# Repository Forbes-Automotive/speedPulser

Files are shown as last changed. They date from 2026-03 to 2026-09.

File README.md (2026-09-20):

# SpeedPulser

The SpeedPulser converts digital speed pulses from a gearbox hall sensor (or a [Can2Cluster](https://forbes-automotive.com) signal) into a 10 kHz PWM signal that drives a BLDC motor — giving life back to an OEM analog speedometer without a mechanical cable. It is fully open-source, WiFi-configurable, and calibrated per cluster type so the needle reads accurately across the available speed range of the motor.

It is based on a **LOLIN C3 Mini (ESP32-C3)** and uses a **TY3816B** BLDC motor driven via a native LEDC hardware PWM channel.

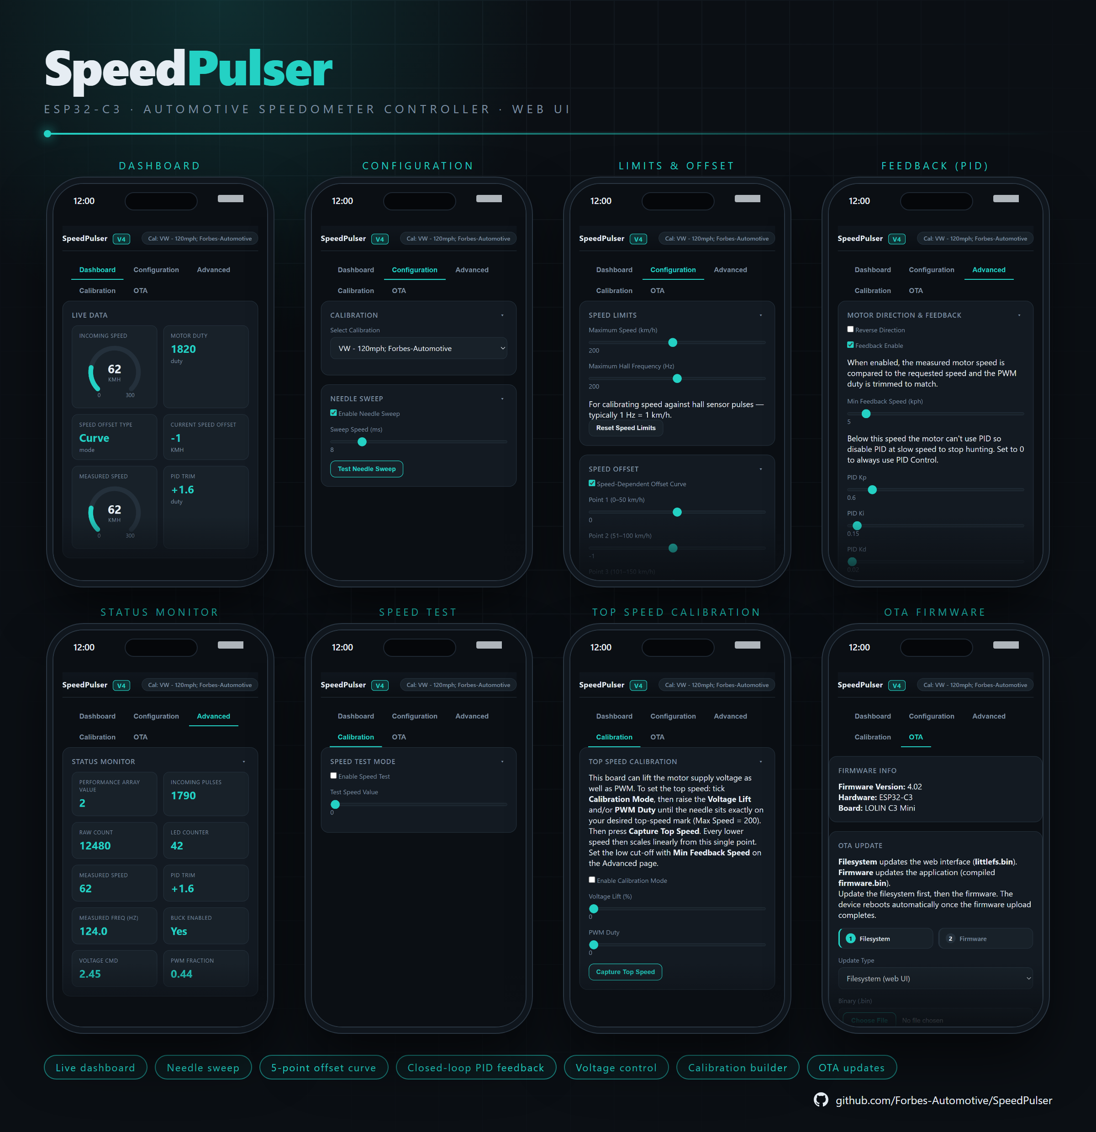
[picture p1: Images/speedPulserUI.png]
SpeedPulser Web UI — dashboard, configuration, limits & offset, PID feedback, status monitor, speed test, top-speed calibration and OTA


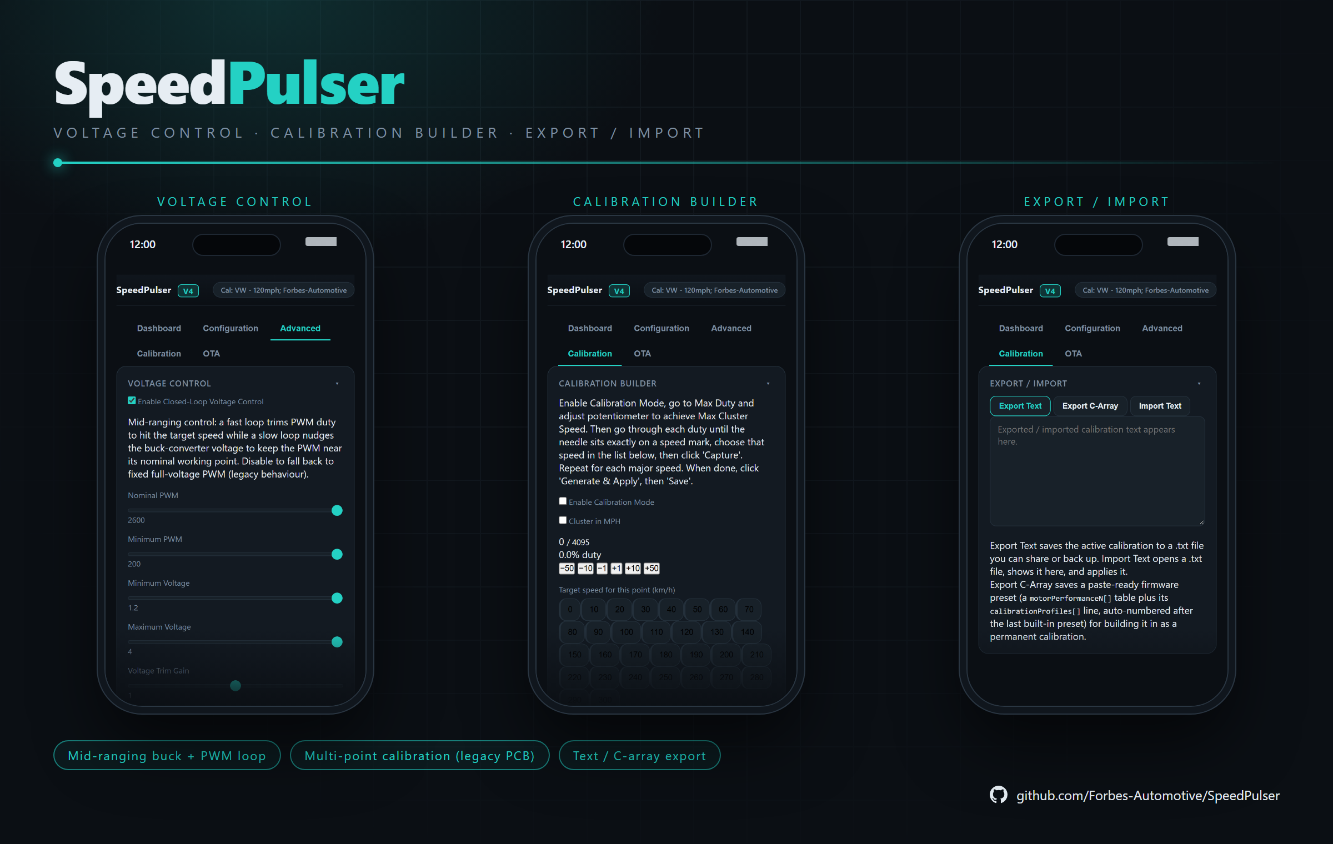
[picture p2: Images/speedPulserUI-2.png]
SpeedPulser Web UI — voltage control, calibration builder and export / import


---

## Features at a Glance

| Feature | Detail |
|---|---|
| Speed input | 5V / 12V square-wave (hall sensor or Can2Cluster) |
| Motor output | 10 kHz hardware PWM, 12-bit resolution |
| Closed-loop feedback | PID trims duty from the motor feedback pin (optional) |
| Calibration profiles | 18 built-in (VW, Ford, Fiat, Merc, Smiths, Opel, VW Bay) |
| Custom calibration | Calibration Builder — capture, generate, save, export/import |
| Calibration Curve | Live duty-vs-speed curve with the current operating point on the Dashboard |
| Status Monitor | Live measured speed, PID trim and actual motor speed (Hz) |
| WiFi UI | Web app type interface |
| Needle sweep | Configurable on power-up |
| Speed offset | Global fixed offset **or** 5-point speed-dependent curve |
| OTA updates | Firmware upload from the browser |
| Power management | Auto WiFi-off + CPU scaling after 1 min idle |
| Remembers settings | All settings stored to ESP32 Preferences (NVS/EEPROM) |

---

## Supported Models

| Cluster | Range | Calibration by |
|---|---|---|
| VW MK1 / MK2 Golf | 120 mph | Martin Springell |
| VW MK1 / MK2 Golf | 120 mph | Forbes Automotive |
| VW MK1 / MK2 Golf | 120 mph | Tara |
| VW MK1 / MK2 Golf | 140 mph | Forbes Automotive |
| VW MK1 / MK2 Golf | 160 mph | Forbes Automotive |
| VW MK1 / MK2 Golf | 300 kph (1.8T) | Forbes Automotive |
| VW Bay VDO | 90 mph | Community |
| Ford Escort | 120 mph (var. 1) | Forbes Automotive |
| Ford Escort | 120 mph (var. 2 — Darren) | Community |
| FIAT Uno | 40–160 mph | Forbes Automotive |
| FIAT Uno | 20–110 mph | Forbes Automotive |
| Mercedes W123 | 120 mph | Forbes Automotive |
| Smiths 5/8" | 70 mph | Forbes Automotive |
| Smiths 5/8" | 90 mph | Forbes Automotive |
| Smiths 5/8" | 150 mph | Forbes Automotive |
| Opel Manta A-72 | 200 km/h | Forbes Automotive |

> Users are actively encouraged to submit new models, calibrations, or corrections via GitHub or Discord.

---

## Purchase

Pre-assembled SpeedPulser units are available here: [SpeedPulser — Forbes Automotive](https://forbes-automotive.com/products/speedpulser)

---

## More Detailed Instructions

The PDF Installation Guide on GitHub provides full step-by-step hardware fitting instructions.

---

## Hardware Overview

### PCB

The pre-assembled PCB:

SpeedPulser Board Overview

---

### Power Supply & Hall Sensor Input

The three-pin **Input** connector on the bottom edge of the PCB accepts 12V battery power and the speed signal:

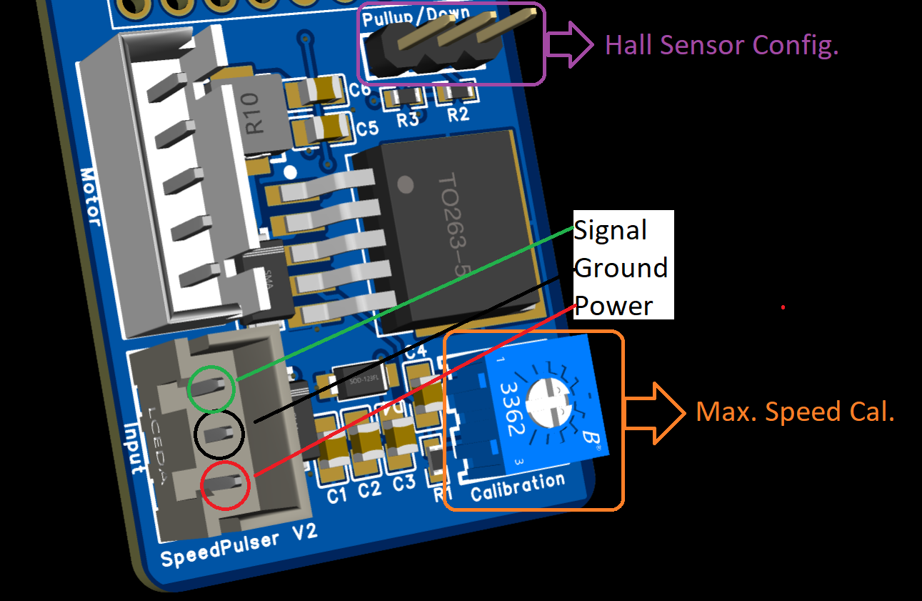
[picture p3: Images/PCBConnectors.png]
PCB Input & Motor Connectors


| Pin | Signal | Notes |
|-----|---|---|
| 1 | PWR_IN (12 V) | Closest to board edge; connect to ignition-switched 12 V |
| 2 | GND | Common ground |
| 3 | Speed Signal | 5 V or 12 V square wave from hall sensor or Can2Cluster |

> **Pull-up / Pull-down jumper:** Different hall sensors require either a pull-up or pull-down resistor. A 2-way jumper header on the PCB selects this. If the SpeedPulser is not registering incoming pulses, swap the jumper position. Sensors with an internal resistor can have the jumper removed entirely.

An on-board adjustable **LM2596S** buck converter steps the 12V supply down to approximately 9V to power the motor, keeping the motor's operating range and torque within spec across the full speed scale.

---

### Motor Connector

The five-pin **Motor** connector on the top edge of the PCB:

| Pin | Signal | Notes |
|-----|---|---|
| 1 | Motor Power | Black — 5–9 V (set via on-board trimmer) |
| 2 | Motor Feedback | White — BLDC feedback pulse; read on GPIO 4 for closed-loop PID (optional) |
| 3 | Motor Direction | Green — LOW (normal); enable Reverse to flip needle direction — HIGH (reversed) |
| 4 | Motor Ground | White — motor ground |
| 5 | Motor PWM | 10 kHz PWM from ESP32 (via NPN level-shifter to 4V) |

---

### Coupler Installation

Motors are supplied with the coupler pre-fitted; the final drive pin and securing pins are included separately.

1. Remove the motor from the coupler housing.
2. Align the drive pin into the coupler recess and press home — a few light taps should seat it fully.
3. A spare coupler is supplied. Couplers are 3D printed; slight alignment variation is normal. A brief gentle heat application (≤ 100 °C) can encourage a true run.
4. If excessive vibration causes the coupler to loosen, a small drop of super-glue will fix it permanently — confirm it runs true before the glue sets.

---

### Trimming the Drive Shaft

Drive shafts are supplied longer than required. Trim to suit your cluster, typically flush with the motor housing. **Confirm the shaft does not bottom out in the cluster before tightening.**

---

### Fine-Tuning the Coupler

Once the motor is assembled, slide it over the OEM cluster shaft. Check:

- The drive pin engages cleanly
- The motor spins freely by hand
- The pin length is sufficient to engage the cluster but does not prevent the housing from seating fully

Take time here — good fitment minimises noise and extends coupler life.

> Couplers are 3D printed and every motor / housing / cluster pairing wears in slightly differently. Expect to revisit the on-board potentiometer once after a few hours of running so the top-end reading still hits full-scale cleanly.

---

## WiFi & Web Interface

Connect to the **`SpeedPulser`** WiFi access point (open network) and navigate to **`192.168.1.1`** or **`speedpulser.local`** in a browser.

The interface is a single-page app served from the ESP32's LittleFS flash partition, built on Forbes Automotive's shared dark theme (the same look used across OpenHaldex, Can2Cluster, SpeedPulserPro, can2rpm, the MQB Steering Wheel Controller and AirLift Controller). Settings are applied in real time and saved to EEPROM automatically every 2 seconds. Current firmware version: **4.01**.

**Status colours:** most tiles use plain text rather than colour, but a per-tile dial gauge (Incoming Speed / Motor Duty) turns **orange/amber** whenever **Speed Test Mode** or **Calibration Mode** is driving the motor — a reminder that the value shown is a synthetic test value, not a live vehicle reading. A missing motor-feedback signal (legacy PCBs without the feedback circuit) shows as plain **N/A** rather than a coloured warning.

### Dashboard Tab

Live read-outs updated automatically:

| Field | Description |
|---|---|
| Incoming Speed | Speed value calculated from incoming hall-sensor pulses (km/h or mph) |
| Motor Duty | PWM duty cycle currently applied to the motor |
| Measured Speed | Speed derived from the motor fedback pin when feedback is enabled |
| PID Trim | Duty correction the feedback loop is currently applying |
| Speed Offset Type | Whether a *Global* or *Curve* offset is active |
| Current Speed Offset | The offset value applied at the current speed |

Below the read-outs is a **Calibration Curve** graph: a duty-vs-speed trace of the
active calibration with its captured points, plus a marker showing the point
currently being achieved — from the hall input, Speed Test Mode or Calibration Mode.

While **Speed Test Mode** is active, these fields switch to show the chosen test speed and resulting motor duty instead.

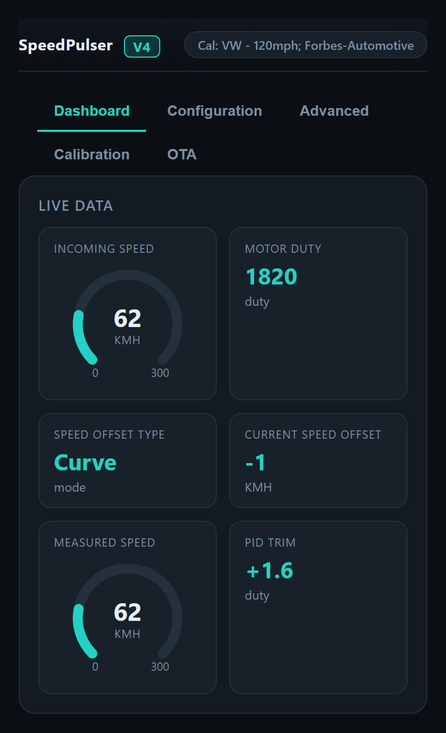
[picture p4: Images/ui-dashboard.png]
Dashboard tab — live data tiles (incoming speed, motor duty, offset type and value, measured speed, PID trim) and the calibration curve graph


> The bright dot on the graph is the point currently being achieved — from the hall input, Speed Test Mode or Calibration Mode — plotted against the active calibration's duty/speed curve (green dots = captured/sampled anchor points).

### Configuration Tab

| Setting | Description |
|---|---|
| Enable Needle Sweep | Triggers a full-scale needle sweep on power-up |
| Sweep Speed (ms) | Step delay in milliseconds: lower = faster sweep |
| Test Needle Sweep | Trigger a sweep immediately from the browser |
| Calibration Selection | Choose from 18 built-in cluster calibration profiles |
| Maximum Speed (km/h) | Upper end of the cluster's speed scale |
| Maximum Hall Frequency (Hz) | The input frequency that corresponds to Maximum Speed |
| Speed Offset Value | Fixed offset added to or subtracted from all speed readings |
| Positive Offset | Direction of the fixed offset (add or subtract) |
| Speed-Dependent Offset Curve | Enable a 5-point curve offset in place of the global offset |
| Cluster in MPH | Convert the km/h input signal to mph before looking up the motor duty |
| Average Filter Samples | Median smoothing window (1–10) for the incoming signal; higher = steadier but slower |

<p align="center">
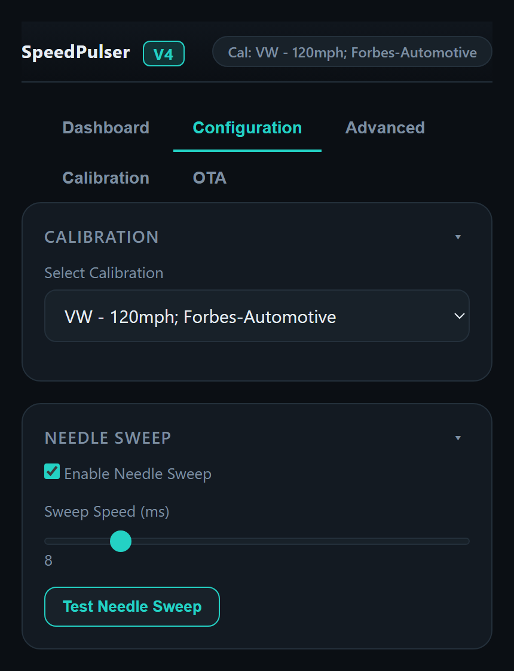
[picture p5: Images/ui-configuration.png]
Configuration tab — calibration selection and needle sweep
  
  &nbsp;&nbsp;
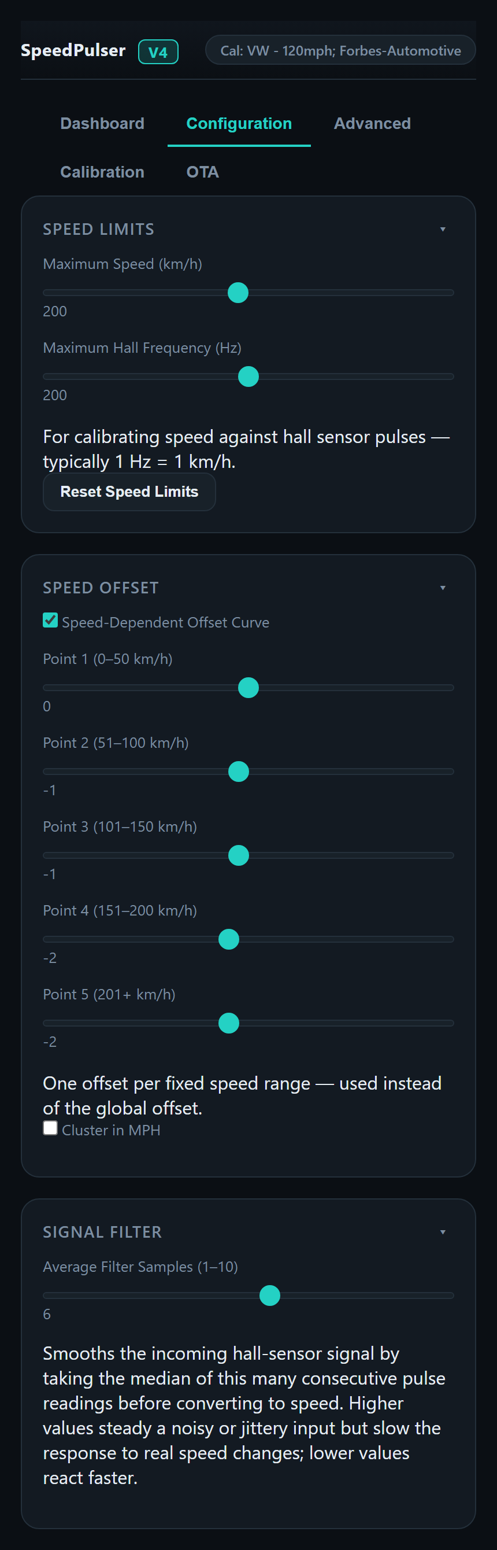
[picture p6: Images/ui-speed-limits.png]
Configuration tab — speed limits, the 5-point speed-dependent offset curve, cluster-in-MPH and the signal filter
  
</p>

*Configuration: calibration profile and needle sweep (left); speed limits, the offset curve (or fixed offset), MPH conversion and the median filter window (right).*

### Advanced Tab

| Setting | Description |
|---|---|
| Reverse Direction | Drive the direction pin HIGH to flip the motor direction |
| Feedback Enable | Turn the closed-loop PID duty trim on or off (**not available on legacy PCBs**) |
| Min Feedback Speed (km/h) | Below this speed the loop runs open-loop (feed-forward only) to stop low-speed hunting; 0 = always closed-loop |
| PID Kp / Ki / Kd | Feedback loop gains (defaults 0.15 / 1.3 / 0) |
| PID Deadband (Hz) | Feedback error (in Hz) ignored by the loop, to stop the needle dithering |
| Reset PID Defaults | Restore the tuned default gains |
| Voltage Control *(V4 PCB only)* | Enable the closed-loop **buck-converter voltage** trim and set its nominal / minimum PWM, voltage range, trim gain and loop gains |
| Performance Array Value | Index of the active calibration array |
| Incoming Pulses | Raw frequency value from the ISR |
| Raw Count | Number of samples accumulated so far |
| LED Counter | ISR pulse counter (also drives the onboard LED blink) |

<p align="center">
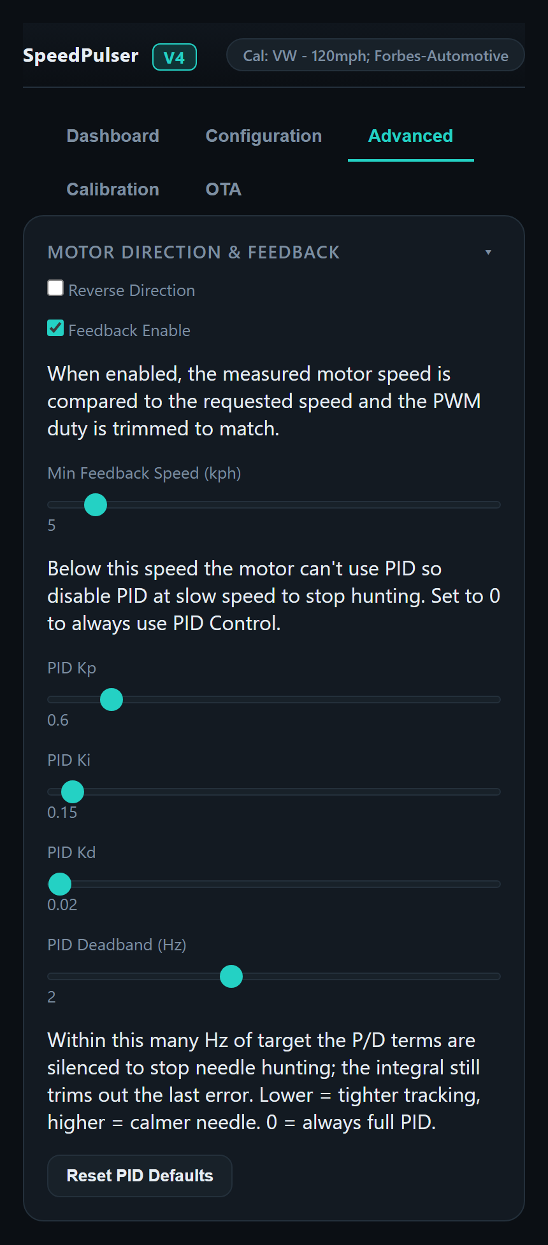
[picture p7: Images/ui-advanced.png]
Advanced tab — motor direction, feedback enable, min feedback speed, PID gains and deadband
  
  &nbsp;&nbsp;
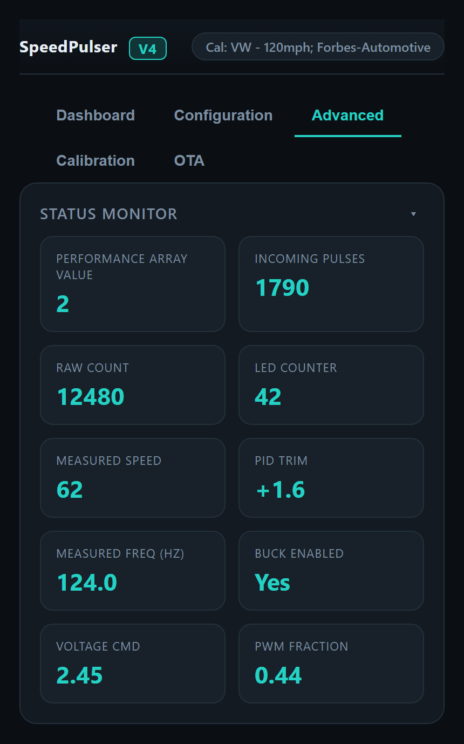
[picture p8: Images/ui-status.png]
Advanced tab — live status monitor: performance array, incoming pulses, raw count, LED counter, measured speed / frequency, PID trim, buck state, voltage command and PWM fraction
  
</p>
> **Reverse Direction** drives GPIO 10 HIGH instead of LOW, flipping the rotation direction for clusters whose motor is mounted the opposite way round.
> **Feedback Enable** turns the closed-loop PID trim on; the sliders below it tune the loop and **Reset PID Defaults** restores the tuned baseline (0.15 / 1.3 / 0). See [Closed-Loop Feedback (PID)](#closed-loop-feedback-pid) below for how it works.

On a **V4 PCB** the Advanced tab also shows **Voltage Control**. This is a mid-ranging scheme: the fast PID loop above trims PWM duty to hit the target speed, while a slow loop nudges the buck-converter voltage so the PWM stays near its **Nominal PWM** working point (between the **Minimum / Maximum Voltage** limits). Turn it off to fall back to fixed full-voltage PWM, i.e. legacy behaviour.

<p align="center">
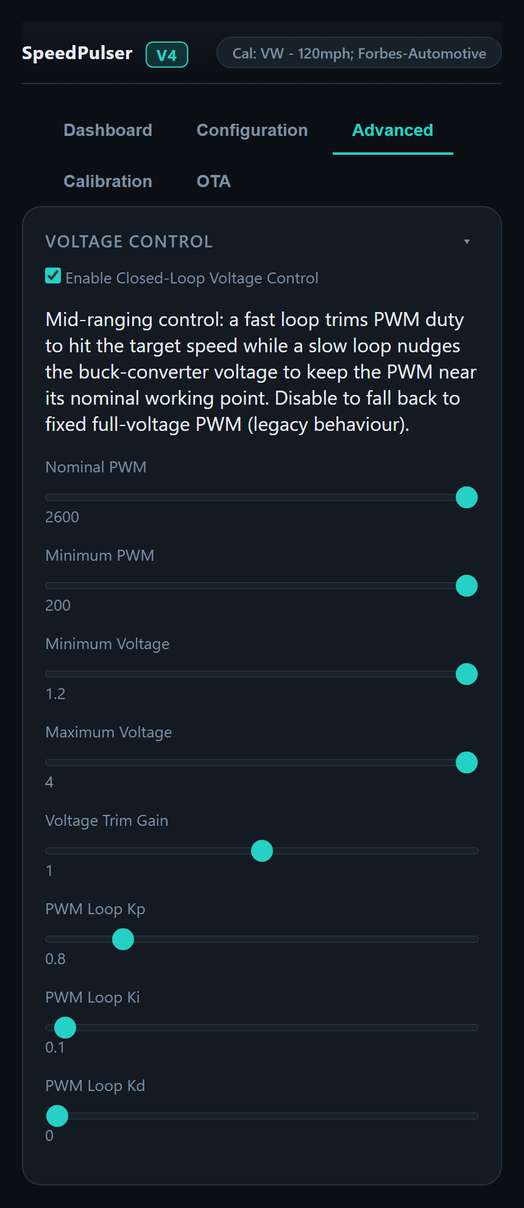
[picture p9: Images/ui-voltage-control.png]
Advanced tab — Voltage Control card: enable, nominal and minimum PWM, minimum / maximum voltage, trim gain and PWM loop gains
  
</p>

### Calibration Tab

Contains **Speed Test Mode**, **Export / Import** and — depending on the board — either the **Top Speed Calibration** card (V4 PCB, which can lift the motor supply voltage) or the multi-point **Calibration Builder** (earlier PCBs).

**Speed Test Mode**  
Locks the motor to a user-chosen speed so the cluster can be observed
without a speed signal. The chosen speed passes through the full offset and
calibration process, to give a realistic preview. With feedback enabled the closed
loop drives to that speed; the dashboard updates in real time to show the chosen speed
and the resulting motor duty.

**Top Speed Calibration** *(V4 PCB)*  
Tick **Enable Calibration Mode**, then raise **Voltage Lift** and/or **PWM Duty** until the
needle sits exactly on the top-speed mark (the Maximum Speed set on the Configuration tab)
and press **Capture Top Speed**. Every lower speed then scales linearly from that single
point; the low cut-off is **Min Feedback Speed** on the Advanced tab.

<p align="center">
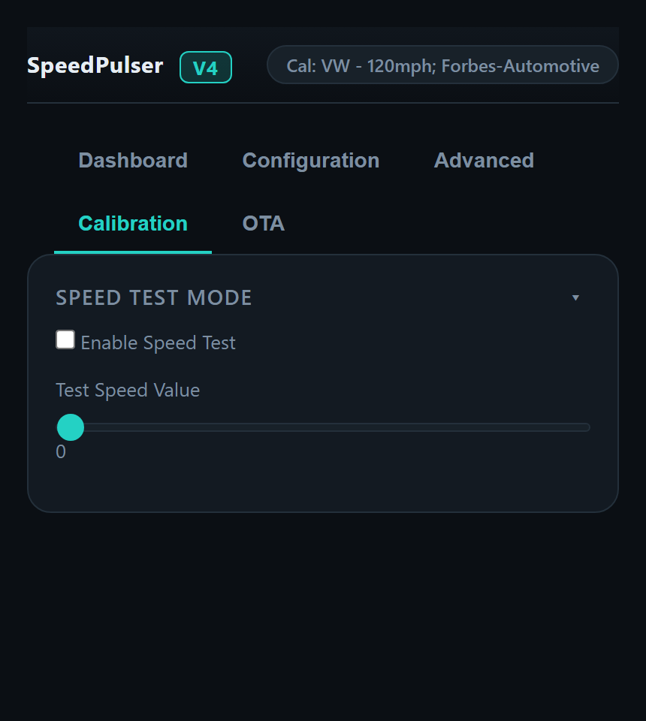
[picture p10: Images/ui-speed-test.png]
Calibration tab — Speed Test Mode with enable and test speed slider
  
  &nbsp;&nbsp;
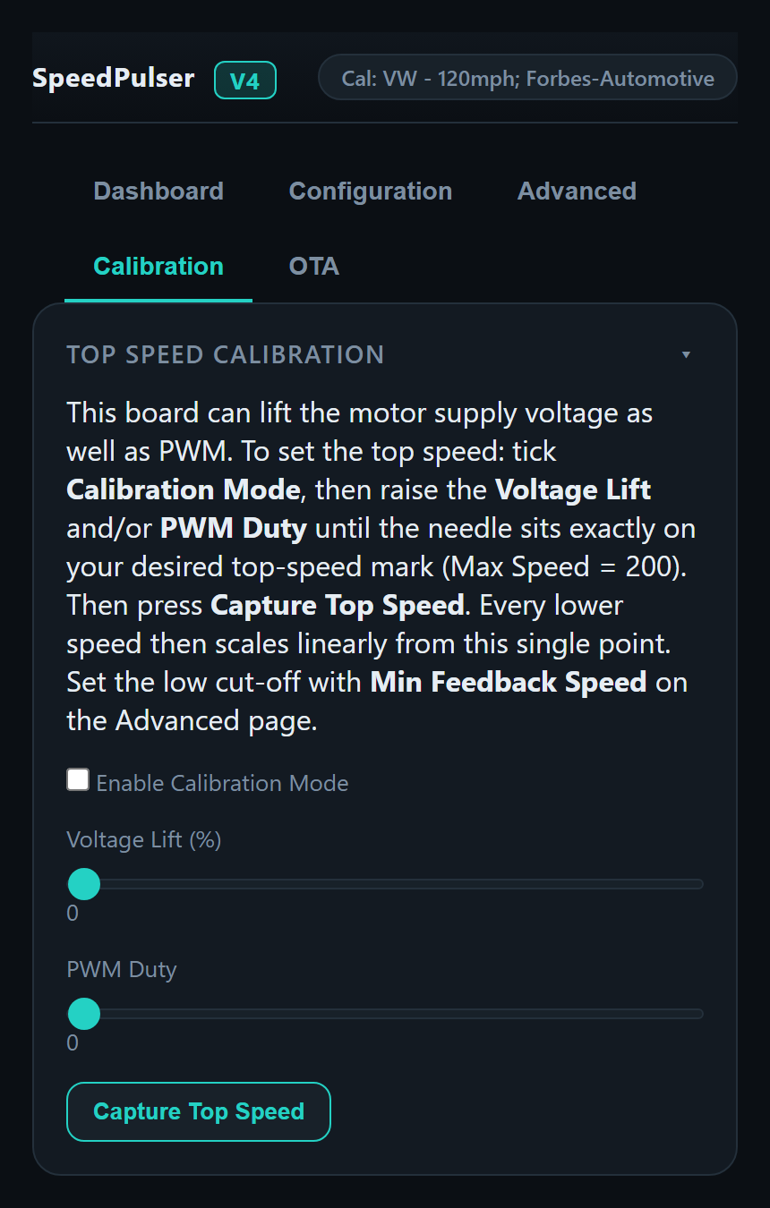
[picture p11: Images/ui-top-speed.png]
Calibration tab — Top Speed Calibration (V4): calibration mode, voltage lift, PWM duty and Capture Top Speed
  
</p>

**Calibration Builder** *(earlier PCBs)*  

1. Tick **Enable Calibration Mode** — the motor now follows the big duty read-out instead
   of the speed source.
2. Change the duty to the maximum value (**4096**).  Adjust the trimmer to achieve maximum cluster value.
3. Change the duty with the **−50 / −10 / −1 / +1 / +10 / +50** buttons until the needle sits exactly on a speed mark.
4. Pick that speed from the **Target speed** or type it in and press **Capture Point**. Each capture
   is listed under *Captured Points* and can be removed individually.
5. Repeat across the scale, name the calibration, then **Generate & Apply** to preview it
   live and **Save to Device** to store it.

**Export / Import**  
**Export Text** saves the active calibration as a `.txt` you can share or back up and
**Import Text** loads one back and applies it. **Export C-Array** writes a paste-ready
firmware preset (a `motorPerformanceN[]` table plus its `calibrationProfiles[]` line) for
building a calibration in permanently.

<p align="center">
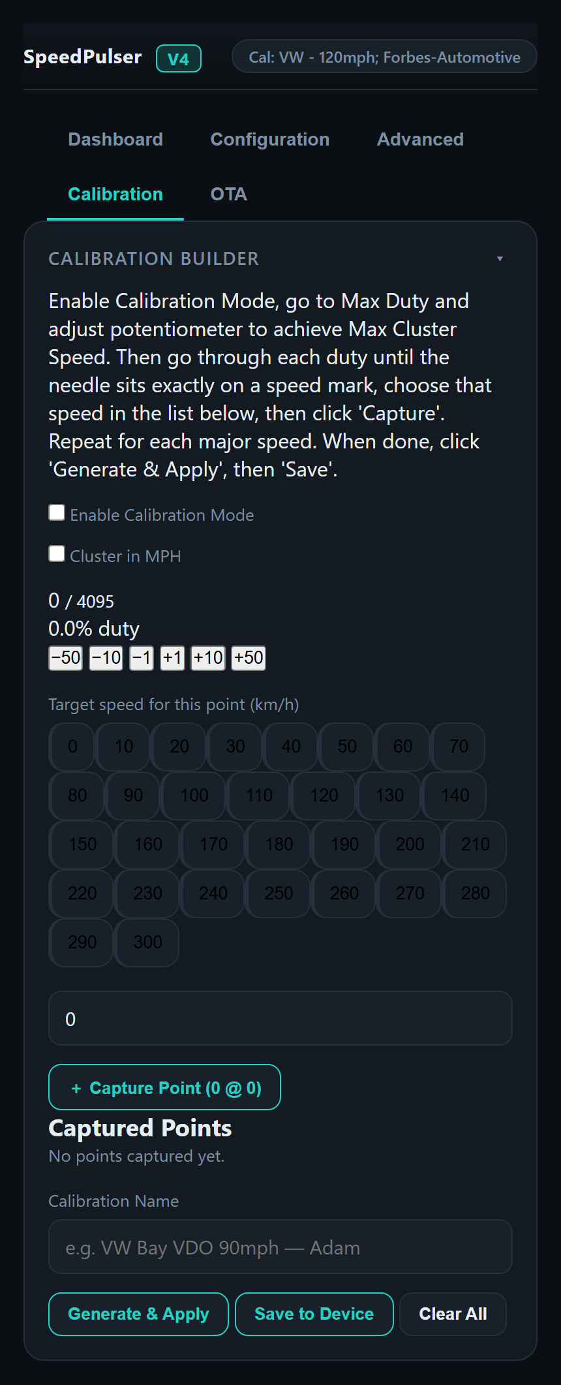
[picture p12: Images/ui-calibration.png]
Calibration tab — Calibration Builder: calibration mode, duty jog buttons, target speed grid, capture point, name, Generate & Apply and Save to Device
  
  &nbsp;&nbsp;
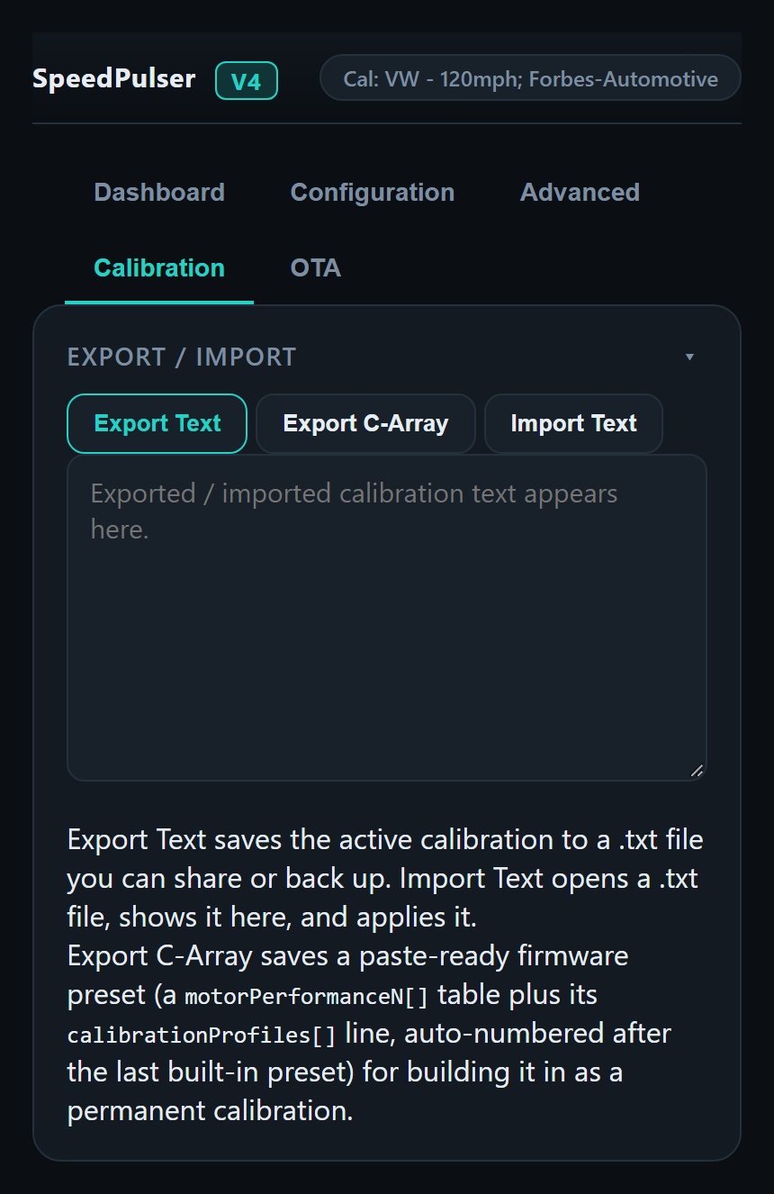
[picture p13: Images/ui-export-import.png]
Calibration tab — Export Text, Export C-Array and Import Text
  
</p>
> Once at least two points are captured, **Generate & Apply** interpolates the full curve and **Save to Device** remembers it — it then appears as the **★ Custom** entry in the Configuration tab's calibration list.

### OTA Tab

Upload a new compiled `.bin` firmware file directly from the browser — no USB cable required. Two steps: the **Filesystem** image (`littlefs.bin`, the web UI) first, then the **Firmware** image (`firmware.bin`); the step tracker marks each as it completes and the device reboots automatically after the firmware step. See [Over-the-Air Updates](#over-the-air-updates-two-step).

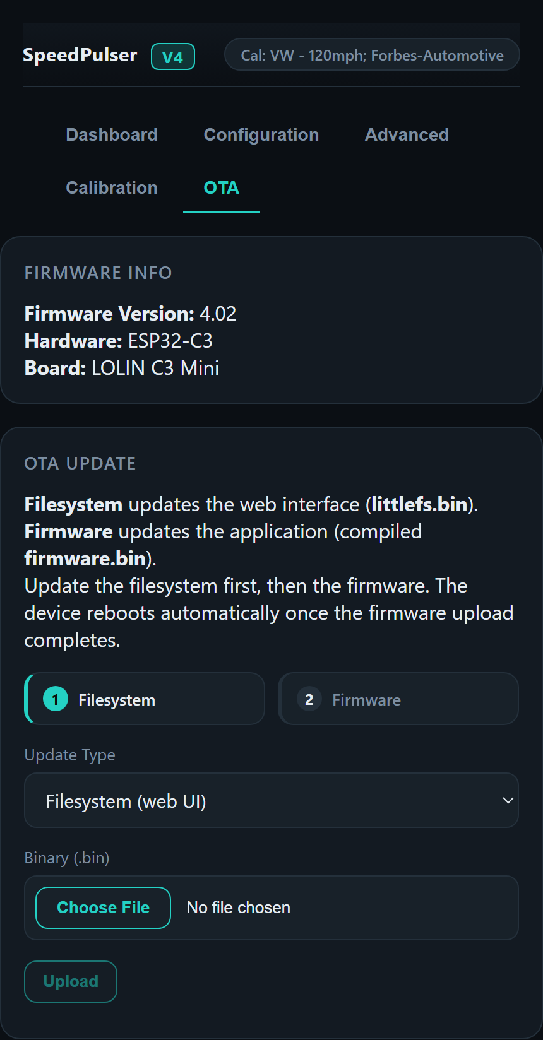
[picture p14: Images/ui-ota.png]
OTA tab — firmware info and the two-step filesystem / firmware uploader


---

## Closed-Loop Feedback (PID)

With **Feedback Enable** on (Advanced tab), the firmware measures the BLDC motor's feedback
pulses and trims the PWM duty so the needle holds its reading under load or voltage sag —
rather than relying on the open-loop calibration alone.

**How It Works**

- The feedback pulse on GPIO4 is counted and converted to a frequency (Hz), then
  smoothed with an exponential moving average.
- The requested speed is converted to a target frequency using a fixed full-scale
  reference (**254 Hz at maximum speed**, measured on the bench and defined into the
  firmware) so the loop needs no per-user frequency calibration.
- A PID controller calculates a duty correction that is added to the feed-forward
  calibration duty. A small dead-band with integral hold prevents needle shudder around
  the target.
- Below **Min Feedback Speed** the loop reverts to open-loop feed-forward to avoid
  low-speed hunting where the motor can't run smoothly.

**Tuning** — the default gains (Kp 0.15, Ki 1.3, Kd 0) suit the supplied motor and
cluster combination; the integral term carries most of the correction. Adjust from the
Advanced tab if needed, and use **Reset PID Defaults** to return to the tuned values.
The Status Monitor shows the live measured speed, the PID trim being applied and the raw
tacho frequency so you can see the loop working.

---

## Calibration — How It Works

### The Calibration Array

Each calibration profile is a **386-element `uint16_t` array** stored in flash (`PROGMEM`). The **array index** represents speed in km/h (0–385) and the **array value** is the 10-bit PWM duty cycle (0–1023) that drives the motor to produce the corresponding reading on that cluster.

```
index   0  →  duty   0   (motor off / dead band)
index  50  →  duty  ~60  (motor at ~50 km/h cluster reading)
index 120  →  duty ~130  (motor at ~120 km/h cluster reading)
  ...
index 200  →  duty ~195  (motor at full scale for a 200 km/h cluster)
```

Values near index 0 are `0` — the motor's dead band where it will not yet turn. Values plateau near the top because the cluster needle is at full deflection.

### Signal Processing 

```
Hall sensor pulse
    │
    ▼  incomingHz()  — windowed capture
    Accumulates each edge interval + count; rejects pulses < 3 ms (> 333 Hz) as noise
    │
    ▼  speedControlTask  (once per loop)
    frequency = intervals ÷ summed interval time   (true average over the window)
    map(frequency, 0, maxFreqHall, 0, maxSpeed)  →  speed in km/h
    │
    ▼  RunningMedian filter  (averageFilter samples, default 6)
    Smoothed median speed value
    │
    ▼  applyConfiguredSpeedOffset()
    Speed ± global offset  OR  speed ± curve offset for that band
    │
    ▼  Optional: × 0.621371  if "Cluster in MPH" is enabled
    │
    ▼  findClosestMatch()
    Scans motorPerformance[] for the closest matching speed value
    Returns the array index = 10-bit duty cycle
    │
    ▼  setMotorDuty()  — native LEDC IDF driver, 10 kHz
    Motor PWM output on GPIO 2
```

> **Windowed frequency capture:** Rather than deriving speed from a single edge-to-edge period — which turns tone-wheel / tooth-spacing jitter straight into a jumpy needle — the ISR accumulates the edge intervals and the task averages them once per window. Pulses closer than ~3 ms (> 333 Hz) are rejected, so ignition-coil EMI can't be mistaken for a valid speed.

> **Default hall-sensor scaling:** 1 Hz = 1 km/h. This matches 02J / 02M gearbox sensors used in most VW/Audi applications. Adjust `maxFreqHall` and `maxSpeed` together if your sensor has a different ratio (e.g. set both to 160 for a sensor that outputs 160 Hz at 160 km/h).

### Reading a Legacy Calibration Array

To check what duty a profile produces at a given speed, index directly:

```cpp
// Direct lookup — returns the 10-bit duty for 80 km/h on the active profile
uint16_t duty = motorPerformance[80];
```

`findClosestMatch()` does the inverse: given a target speed value, it walks the array to find the entry whose **value** is closest to the target and returns the **index** as the duty cycle. This gracefully handles calibration arrays that are not perfectly monotone.

---

## Speed Offset

Two offset modes are available and are both configured from the **Configuration** tab.

**Global Offset** (default)  
A single fixed value is added to or subtracted from every speed reading before the calibration lookup. Useful for correcting a systematic bias across the whole scale caused by motor preload or cluster wear.

**5-Point Curve**  
Five independent offsets replace the global offset when enabled. This corrects clusters whose response is non-linear and cannot be fixed by a single constant.

| Point | Speed band |
|---|---|
| 1 | 0 – 50 km/h |
| 2 | 50 – 100 km/h |
| 3 | 100 – 150 km/h |
| 4 | 150 – 200 km/h |
| 5 | 200+ km/h |

Each point accepts ±20 km/h. Enable the *Speed-Dependent Offset Curve* checkbox on the Configuration tab to activate.

---

## Power Management

The firmware includes a **universal reduced-power codeblock** (`power_manager` - used in SpeedPulser Pro, Can2Cluster and other projects) that activates automatically 1 minute after the last WiFi client disconnects. This cuts current through the on-board linear regulator, directly reducing its heat output — important for long ignition-on times.

**What changes when idle:**

| Action | Saving |
|---|---|
| WiFi radio off | ~80–120 mA average (single biggest saving) |
| CPU: 160 MHz → 80 MHz | Moderate reduction in active current |
| Bluetooth controller released at boot | ~60 KB RAM freed; small idle current saving |
| WiFi modem-sleep while clients are connected | Minor saving without losing connectivity |
| Reduced WiFi TX power | Adequate for in-car range; further small saving |

**Waking back up:**  
As soon as a device reconnects to the WiFi AP, full power is restored automatically — the radio comes back up, the CPU returns to 160 MHz, and the web server resumes. A power-cycle (ignition off/on) will also restore WiFi.

> The LOLIN C3 Mini's maximum CPU frequency is 160 MHz; the power manager auto-detects this at compile time and adjusts accordingly.

---

## Over-the-Air Updates (Two-Step)

New firmware can be flashed without removing the unit from the vehicle. Firmware and the web UI live on separate flash partitions, so updating is a **two-step process** using the shared `ota_manager` module:

1. **Filesystem** — in the **OTA** tab, select **Filesystem (web UI)** and upload `littlefs.bin` (`POST /api/ota/fs`, written to the SPIFFS partition). This updates `index.html` / `app.js` / `style.css`; the device does **not** reboot after this step, so you can go straight on to step 2.
2. **Firmware** — select **Firmware (application)** and upload `firmware.bin` (`POST /api/ota`, written to the OTA app partition). The device reboots automatically once this completes.

Steps in full:

1. Build the project in PlatformIO → locate `firmware.bin` in `.pio/build/lolin_c3_mini/` and `littlefs.bin` under the filesystem build output.
2. Connect to the `SpeedPulser` WiFi AP (or `speedpulser.local`).
3. Open the **OTA** tab in the browser.
4. Upload the filesystem image first, then the firmware image.
5. The device flashes and reboots automatically after the firmware step.

`GET /api/ota/info` reports the running version, board and hardware.

---

## Technical Reference

### Pin Assignments (LOLIN C3 Mini)

| GPIO | Function |
|---|---|
| 2 | Motor PWM output (LEDC 12-bit, stepped to 5 V via NPN transistor) |
| 4 | Motor tacho feedback input (falling-edge interrupt counter; used by the PID loop) |
| 5 | Speed pulse input (falling-edge interrupt) |
| 8 | Onboard LED (blinks to confirm incoming pulses) |
| 10 | Motor direction (LOW = normal, HIGH = reversed) |

### PWM Parameters

| Parameter | Value |
|---|---|
| Frequency | 10 kHz |
| Resolution | 12-bit (0–4095) |
| Driver | Native ESP-IDF `ledc_set_duty` / `ledc_update_duty` |

> Built-in calibration tables were captured at 10-bit and are scaled up to the 12-bit
> hardware domain automatically; the Calibration Builder captures new points at full
> 12-bit resolution.

### FreeRTOS Tasks

| Task | Core | Period |
|---|---|---|
| `speedControlTask` | 0 | Continuous loop |
| `eepromTask` | 0 | 2 000 ms |
| `powerManagerTask` | 0 | 5 000 ms check interval |

### PlatformIO Dependencies

| Library | Purpose |
|---|---|
| `mathieucarbou/ESPAsyncWebServer` | Async web server (ESP-IDF 5.x compatible fork) |
| `mathieucarbou/AsyncTCP` | Underlying TCP for AsyncWebServer |
| `bblanchon/ArduinoJson` | JSON serialisation for REST API |
| `RobTillaart/RunningMedian` | Median filter for speed smoothing |

Platform: `pioarduino/platform-espressif32` (Arduino-ESP32 3.x / ESP-IDF 5.x)

---

## Building & Flashing

1. Open the project folder in VS Code with the PlatformIO extension installed.
2. Confirm `env:lolin_c3_mini` is selected in `platformio.ini`.
3. **Build Filesystem Image** (PlatformIO sidebar) — packages the web UI files from `data/` into a LittleFS image.
4. **Upload Filesystem Image** — flashes the web UI to the SPIFFS/LittleFS partition.
5. **Build & Upload** — flashes the main firmware.
6. Open the Serial Monitor at 115 200 baud to confirm startup messages.

> Serial debug output is controlled by `-D serialDebug=1` in `platformio.ini`. Set to `0` for production builds to avoid stalling if no USB-CDC host is connected.

---

## Version History

| Version | Summary |
|---|---|
| V1.01 | Initial release |
| V1.05 | Global speed offset |
| V1.06 | Pulse timeout / reset-to-zero |
| V1.07 | 160 mph MK2 Golf calibration (Charlie) |
| V1.09 | Martin Springell MK1 Golf calibration |
| V1.11 | WiFi settings page |
| V1.12 | Mercedes W123 calibration |
| V1.13 | Calibration selection in WiFi |
| V1.15 | Calibration test mode via WiFi |
| V1.17 | Smiths 70 mph calibration |
| V1.18 | Over-the-Air updates |
| V1.19 | Smiths 90 mph calibration |
| V2.00 | Ported to PlatformIO |
| V2.10 | LEDC hardware PWM; FreeRTOS tasks; new REST API tabbed web UI; power management module |
| V2.20 | "Cluster in MPH" conversion option |
| V2.21 | Fixed LEDC driver for Arduino-ESP32 3.x (`ledc_set_duty` / `ledc_update_duty`) |
| V3.00 | PCB revision to include Motor Feedback + Reverse option and two Buck Converters (one for the motor, one for the ESP32) |
| V3.01 | PID Calibration, Calibration Builder + Calibration Curve |
| V3.02 | Smoother needle sweep | 
| V3.0x | Various multiple tweaks |
| V3.10 | Tighter PID control, feedback check for legacy PCBs etc |

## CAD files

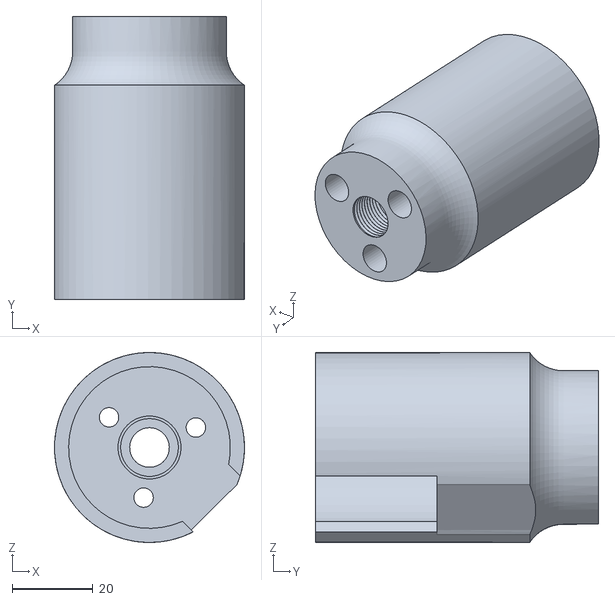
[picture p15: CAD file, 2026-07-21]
Motor Support Model/Volvo/VolvoSpeedoAdapter-M12x1.0Narrow.STL
47.0 x 70.0 x 47.0

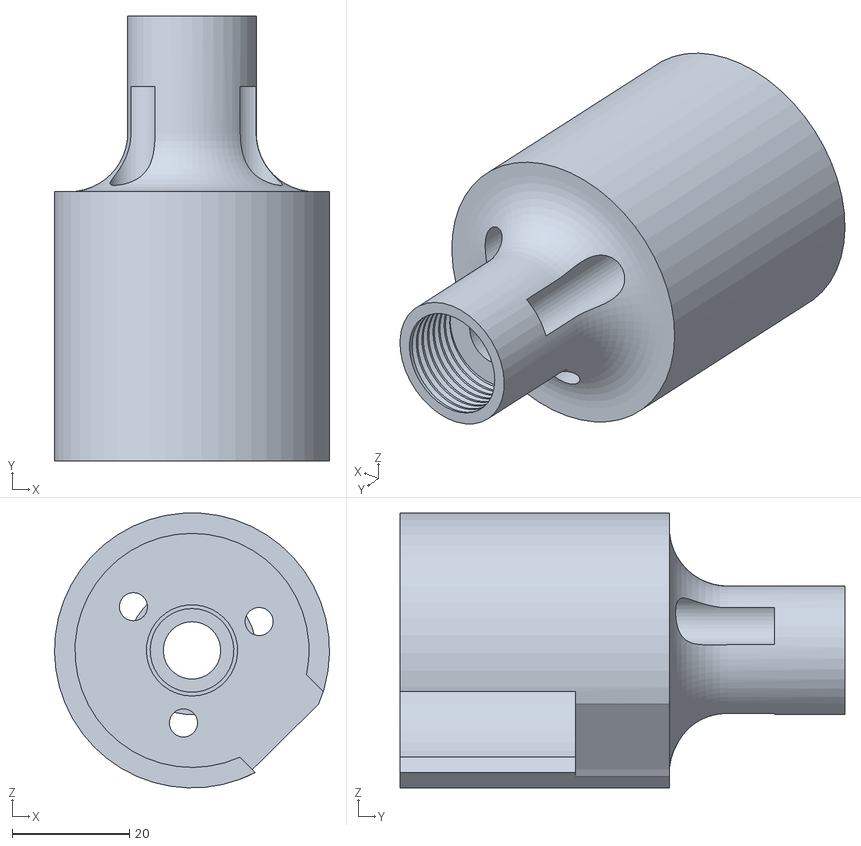
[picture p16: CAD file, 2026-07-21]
Motor Support Model/Volvo/VolvoM18.STL
47.0 x 76.0 x 46.9

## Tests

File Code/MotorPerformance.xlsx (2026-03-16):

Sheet: uint8_t
Duty Cycle (Motor) | Resulting Speed (kmh)
1 | 0
2 | 0
3 | 0
4 | 25
5 | 32
6 | 34
7 | 39
8 | 42
9 | 46
10 | 50
11 | 53
12 | 58
13 | 62
14 | 65
15 | 70
16 | 73
17 | 78
18 | 80
19 | 83
20 | 88
21 | 90
22 | 92
23 | 96
24 | 99
25 | 102
26 | 105
27 | 108
28 | 109
29 | 111
30 | 113
31 | 115
32 | 118
33 | 120
34 | 122
35 | 123
36 | 125
37 | 128
38 | 130
39 | 131
40 | 135
41 | 136
42 | 138
43 | 140
44 | 141
45 | 143
46 | 144
47 | 148
48 | 150
49 | 151
50 | 152
51 | 153
52 | 154
53 | 158
54 | 159
55 | 160
56 | 162
57 | 163
58 | 164
59 | 165
60 | 166
61 | 167
62 | 168
63 | 169
64 | 170
65 | 171
66 | 172
67 | 175
68 | 176
69 | 178
70 | 179
71 | 179
72 | 180
73 | 181
74 | 182
75 | 183
76 | 185
77 | 186
78 | 187
79 | 188
80 | 188
81 | 188
82 | 188
83 | 189
84 | 190
85 | 190
86 | 191
87 | 191
88 | 192
89 | 192
90 | 193
91 | 193
92 | 194
93 | 194
94 | 195
95 | 196
96 | 197
97 | 198
98 | 199
99 | 200
100 | 200
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

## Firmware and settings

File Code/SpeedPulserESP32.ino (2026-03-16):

/*
SpeedPulser - Forbes Automotive '25
Analog speed converter suitable for mechnical drive speedometers.  Tested on VW, Ford & Fiat clusters, the only change is the CAD model. Likely compatible with other marques.  

Inputs are a 5v/12v square wave input from Can2Cluster or an OEM Hall Sensor and converts it into a PWM signal for a BLDC motor.  To get speeds low enough, the motor voltage needs reduced (hence the adjustable LM2596S on the PCB)
from 12v to ~9v.  This allows <10mph readings while still allowing high (160mph) readings.  Clusters supported are 1540 (rotations per mile) =~ (1540*160)/60 = 4100rpm

Default support is for 12v hall sensors from 02J / 02M etc: 1Hz = 1km/h.  Other marques may have different calibrations (adjustable in '_defs.h')

Motor performance plotted with Duty Cycle & Resulting Speed.  Basic Excel located in GitHub for reference - the motor isn't linear so it cannot be assumed that x*y duty = z speed(!)
LED PWM can use various 'bits' for resolution.  8 bit results in a poorer resolution, therefore the speed can be 'jumpy'.  Default is 10 bit which makes it smoother.  Both are available but 10 bit is default.

Uses 'ESP32_FastPWM' for easier PWM control compared to LEDc
Uses 'RunningMedian' for capturing multiple input pulses to compare against.  Used to ignore 'outliars'

To calibrate or adapt to other models:
> Use WiFi to enable calibration, use 'Previous' to set to 385 duty - adjust blue potentiometer to maximum speed on cluster.  Run through each duty (using 'Next'), noting down each duty vs. speed
> Copy each resulting speed into new 'motorPerformance'
> Comment out the current motorPerformance and uncomment yours
> Adjust 'maxSpeed' to suit new range 
> Done!

All main adjustable variables are in '_defs.h'.
*/

#include "SpeedPulserESP32_defs.h"

ESP32_FAST_PWM* motorPWM;                              // for PWM control.  ESP Boards need to be V2.0.17 - the latest version has known issues with LEDPWM(!)
RunningMedian samples = RunningMedian(averageFilter);  // for calculating median samples - there can be 'hickups' in the incoming signal, this helps remove them(!)
TickTwo tickEEP(writeEEP, eepRefresh);
TickTwo tickWiFi(disconnectWifi, wifiDisable);  // timer for disconnecting wifi after 30s if no connections - saves power
Preferences pref;
ESPAsyncHTTPUpdateServer updateServer;

// interrupt routine for the incoming pulse from opto
void incomingHz() {                                               // Interrupt 0 service routine
  static unsigned long previousMicros = micros();                 // remember variable, initialize first time
  unsigned long presentMicros = micros();                         // read microseconds
  unsigned long revolutionTime = presentMicros - previousMicros;  // works fine with wrap-around of micros()
  if (revolutionTime < 1000UL) return;                            // avoid divide by 0, also debounce, speed can't be over 60,000 was 1000UL
  dutyCycleIncoming = (60000000UL / revolutionTime) / 60;         // calculate
  previousMicros = presentMicros;
  lastPulse = millis();

  ledCounter++;  // count LED counter - is used to flash onboard LED to show the presence of incoming pulses
}

void setup() {
#ifdef serialDebug
  Serial.begin(baudSerial);
  DEBUG_PRINTLN("Initialising SpeedPulser...");
#endif

  readEEP();           // read the EEPROM for previous saved states
  tickEEP.start();     // begin ticker for the EEPROM
  tickWiFi.start();    // begin ticker for the WiFi (to turn off after 60s)
  updateMotorArray();  // update the motor array with the stored value from EEP

  basicInit();                                                // init PWM, Serial, Pin IO etc.  Kept in '_io.ino' for cleanliness due to the number of Serial outputs
  motorPWM->setPWM(pinMotorOutput, pwmFrequency, dutyCycle);  // set motor to off in first instance (0% duty)

  if (hasNeedleSweep) {
    needleSweep();  // enable needle sweep (in _io.ino)
  }

  connectWifi();                       // enable / start WiFi
  WiFi.setSleep(false);                //For the ESP32: turn off sleeping to increase UI responsivness (at the cost of power use)
  setupUI();                           // setup wifi user interface
  setupOTA();                          // setup Over-the-Air updates
  WiFi.setTxPower(WIFI_POWER_8_5dBm);  // some C3 boards require a lower Tx power otherwise it won't appear

  updateLabels();  // set base values for WiFi
}

void loop() {
  tickEEP.update();   // refresh the EEP ticker
  tickWiFi.update();  // refresh the WiFi ticker

  if (ledCounter > averageFilter) {           // only flip-flop the LED every time the filter is filled.  This will reduce the 'on' time of the LED making it easier to see!
    ledOnboard = !ledOnboard;                 // flip-flop the led trigger
    digitalWrite(pinOnboardLED, ledOnboard);  // toggle the LED to show the presence of incoming pulses
    ledCounter = 0;                           // reset the counter
  }

  // reset speed to zero if >durationReset
  if (((millis() + 10) - lastPulse) > durationReset) {
    if (!testSpeedo && !testCal) {
      motorPWM->setPWM_manual(pinMotorOutput, 0);
      ESPUI.updateLabel(label_speed, "Speed: 0");
    }
  }

  if (testNeedleSweep) {  // for flag set in WiFi for testing needle sweep
    needleSweep();
    testNeedleSweep = false;
  }

  if (updateMotorPerformance) {  // only refresh the motor array if cal. changed
    updateMotorArray();
  }

  // check to see if in 'test mode' (testSpeedo = 1)
  if (testSpeedo || testCal) {
    testSpeed();  // if tempSpeed > 0, set to fixed duty, else, run through available duties
  }

  if (!testSpeedo && !testCal) {
    if (dutyCycle != dutyCycleIncoming) {  // only update PWM IF speed has changed (can cause flicker otherwise)
      DEBUG_PRINTF("     DutyIncomingHall: %d", dutyCycleIncoming);
      dutyCycleIncoming = map(dutyCycleIncoming, 0, maxFreqHall, 0, maxSpeed);  // map incoming range to this codes range.  Max Hz should match Max Speed - i.e., 200Hz = 200kmh, or 500Hz = 200kmh...
      DEBUG_PRINTF("     DutyPostProc1Hall: %d", dutyCycle);

      if (rawCount < averageFilter) {
        samples.add(dutyCycleIncoming);
        rawCount++;
      }

      if (rawCount >= averageFilter) {
        dutyCycle = samples.getMedian();
        //dutyCycle = samples.getAverage();
        DEBUG_PRINTF("     getAverageHall: %d", dutyCycle);
        char buf[32];
        sprintf(buf, "Speed: %d", dutyCycle);
        ESPUI.updateLabel(label_speed, String(buf));

        if (speedOffsetPositive) {
          dutyCycle = dutyCycle + speedOffset;
          dutyCycle = dutyCycle * speedMultiplier;
          if (convertToMPH) {
            dutyCycle = dutyCycle * mphFactor;
          }
          dutyCycle = findClosestMatch(dutyCycle);
          motorPWM->setPWM_manual(pinMotorOutput, dutyCycle);
        } else {
          if (dutyCycle - speedOffset > 0) {
            dutyCycle = dutyCycle - speedOffset;
            dutyCycle = dutyCycle * speedMultiplier;
            if (convertToMPH) {
              dutyCycle = dutyCycle * mphFactor;
            }
            dutyCycle = findClosestMatch(dutyCycle);
            motorPWM->setPWM_manual(pinMotorOutput, dutyCycle);
          } else {
            motorPWM->setPWM_manual(pinMotorOutput, 0);
          }
        }

        DEBUG_PRINTF("     FindClosetMatchHall: %d", dutyCycle);
        rawCount = 0;
        samples.clear();
      }
    }
    dutyCycle = dutyCycleIncoming;  // re-introduce?  Could do some filter on big changes?  May skip over genuine changes though?
  }
}

uint16_t findClosestMatch(uint16_t val) {
  // for finding the nearest match of speed from the incoming duty.  There may be instances where the incoming speed does not equal a value in the array, so find the 'nearest' value
  // has to be 16_t due to 10 bit resolution
  // the 'find'/function returns array position, which is equal to the duty cycle
  uint16_t closest = 0;
  uint16_t closest2 = 0;
  uint16_t i = 0;
  bool speedTest = false;

  for (i = 0; i < sizeof motorPerformance / sizeof motorPerformance[0]; i++) {
    if (motorPerformance[i] > 0) {
      if (abs(val) > motorPerformance[i]) {
        speedTest = true;
        i = (sizeof motorPerformance / sizeof motorPerformance[0]);
      }
    }
  }

  if (speedTest) {
    for (i = 0; i < sizeof motorPerformance / sizeof motorPerformance[0]; i++) {
      if (abs(val - closest) >= abs(val - motorPerformance[i])) {
        closest = motorPerformance[i];
      }
    }

    for (i = 0; i < sizeof motorPerformance / sizeof motorPerformance[0]; i++) {
      if (motorPerformance[i] == closest) {
        closest2 = i;
        i = (sizeof motorPerformance / sizeof motorPerformance[0]);
      }
    }

    if (closest2 >= 385) {  // will run into the end of the array IF it's not found a speed, so return 0!
      return 0;
    } else {
      return closest2;  // else return the correct duty cycle from the found speed
    }
  } else {
    return 0;
  }
}

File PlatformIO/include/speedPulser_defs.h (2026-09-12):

#ifndef SPEED_PULSER_DEFS_H
#define SPEED_PULSER_DEFS_H

#include <Arduino.h>
#include <driver/ledc.h>   // for LEDC PWM (hardware PWM)
#include <RunningMedian.h> // for calculating median
#include <Preferences.h>   // for eeprom/remember settings
#include <WiFi.h>          // for WiFi interface
#include <ESPmDNS.h>       // for WiFi interface
#include <LittleFS.h>      // for serving static files

// for Web Server
#include <AsyncTCP.h>
#include <ESPAsyncWebServer.h>
#include <ArduinoJson.h> // for UI/API JSON handling

// Create global AsyncWebServer instance
extern AsyncWebServer server;

// ---------------------------------------------------------------------------
// Serial debug — output per major subsystem
//
//   * enableDebug is the SINGLE master control. Set it to 0 to silence EVERY
//     serial debug statement.
//   * With enableDebug = 1, toggle the per-subsystem flags below to pick which
//     tagged Serial streams you want.
//   * Every subsystem gets DEBUG_xxx(...) (adds a newline) and DEBUG_xxx_(...)
//     (no newline) printf-style macros, each prefixed with a [TAG] so the log
//     is neat and easy to follow.
// ---------------------------------------------------------------------------
#define enableDebug 0 // ** Main ** 0 = silence ALL serial debug

#define debugSys 1   // [SYS]  boot / general / 1 Hz loop
#define debugPower 1 // [PWR]  power_manager (reduced power / wake)
#define debugWifi 1  // [WiFi] soft-AP + web server bring-up
#define debugIO 1    // [IO]   GPIO / LEDC PWM / interrupt init
#define debugEEP 1   // [EEP]  EEPROM / Preferences load & save
#define debugCtrl 1  // [CTRL] speed input / duty mapping
#define debugFB 1    // [FB]   closed-loop feedback / PID diagnostics
#define debugWeb 1   // [WEB]  web server / API / UI / OTA

#ifndef baudSerial
#define baudSerial 115200 // serial monitor baud rate
#endif

// --- [SYS] master / general (uncategorised) ---
#if enableDebug && debugSys
#define DEBUG(x, ...) Serial.printf("[SYS] " x "\n", ##__VA_ARGS__)
#define DEBUG_(x, ...) Serial.printf("[SYS] " x, ##__VA_ARGS__)
#else
#define DEBUG(x, ...)
#define DEBUG_(x, ...)
#endif

// --- [PWR] power management ---
#if enableDebug && debugPower
#define DEBUG_PWR(x, ...) Serial.printf("[PWR] " x "\n", ##__VA_ARGS__)
#define DEBUG_PWR_(x, ...) Serial.printf("[PWR] " x, ##__VA_ARGS__)
#else
#define DEBUG_PWR(x, ...)
#define DEBUG_PWR_(x, ...)
#endif

// --- [WiFi] soft-AP + web server ---
#if enableDebug && debugWifi
#define DEBUG_WIFI(x, ...) Serial.printf("[WiFi] " x "\n", ##__VA_ARGS__)
#define DEBUG_WIFI_(x, ...) Serial.printf("[WiFi] " x, ##__VA_ARGS__)
#else
#define DEBUG_WIFI(x, ...)
#define DEBUG_WIFI_(x, ...)
#endif

// --- [IO] GPIO / LEDC PWM / interrupt init ---
#if enableDebug && debugIO
#define DEBUG_IO(x, ...) Serial.printf("[IO] " x "\n", ##__VA_ARGS__)
#define DEBUG_IO_(x, ...) Serial.printf("[IO] " x, ##__VA_ARGS__)
#else
#define DEBUG_IO(x, ...)
#define DEBUG_IO_(x, ...)
#endif

// --- [EEP] EEPROM / Preferences ---
#if enableDebug && debugEEP
#define DEBUG_EEP(x, ...) Serial.printf("[EEP] " x "\n", ##__VA_ARGS__)
#define DEBUG_EEP_(x, ...) Serial.printf("[EEP] " x, ##__VA_ARGS__)
#else
#define DEBUG_EEP(x, ...)
#define DEBUG_EEP_(x, ...)
#endif

// --- [CTRL] speed input / duty mapping ---
#if enableDebug && debugCtrl
#define DEBUG_CTRL(x, ...) Serial.printf("[CTRL] " x "\n", ##__VA_ARGS__)
#define DEBUG_CTRL_(x, ...) Serial.printf("[CTRL] " x, ##__VA_ARGS__)
#else
#define DEBUG_CTRL(x, ...)
#define DEBUG_CTRL_(x, ...)
#endif

// --- [FB] closed-loop feedback / PID diagnostics ---
#if enableDebug && debugFB
#define DEBUG_FB(x, ...) Serial.printf("[FB] " x "\n", ##__VA_ARGS__)
#define DEBUG_FB_(x, ...) Serial.printf("[FB] " x, ##__VA_ARGS__)
#else
#define DEBUG_FB(x, ...)
#define DEBUG_FB_(x, ...)
#endif

// --- [WEB] web server / API / UI / OTA ---
#if enableDebug && debugWeb
#define DEBUG_WEB(x, ...) Serial.printf("[WEB] " x "\n", ##__VA_ARGS__)
#define DEBUG_WEB_(x, ...) Serial.printf("[WEB] " x, ##__VA_ARGS__)
#else
#define DEBUG_WEB(x, ...)
#define DEBUG_WEB_(x, ...)
#endif

// --- Legacy Serial: kept so any un-migrated call site still compiles, routed
//     through the master. Prefer to use the tagged DEBUG_xxx macros above. ---
#if enableDebug
extern bool serialActive; // true only when a Serial host is connected
#define DEBUG_PRINT(x) Serial.print(x)
#define DEBUG_PRINTF(...) Serial.printf(__VA_ARGS__)
#define DEBUG_PRINTLN(x) Serial.println(x)
#else
#define DEBUG_PRINT(x)
#define DEBUG_PRINTF(...)
#define DEBUG_PRINTLN(x)
#endif

// Legacy for the old flag names (in case anything still tests them).
#ifndef serialDebug
#define serialDebug (enableDebug && debugSys)
#endif
#ifndef serialDebugWifi
#define serialDebugWifi (enableDebug && debugWifi)
#endif

#define eepRefresh 2000   // EEPROM Refresh in ms
#define wifiDisable 60000 // turn off WiFi in ms
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

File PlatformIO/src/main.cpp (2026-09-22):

#include "Arduino.h"
#include "speedPulser_defs.h"
#include "speedPulser_ver.h"
#include "speedPulser_control.h"
#include "speedPulser_tasks.h"
#include "speedPulser_calBuilder.h"
#include "speedPulser_voltage.h"
#include "power_manager.h"
#include "wifi_manager.h"

/*
SpeedPulser - Forbes Automotive '26
Analog speed converter suitable for mechanical drive speedometers.

Tested on VW, Ford, Fiat, Mercedes & Jaguar clusters.

Inputs are a 5v/12v square wave input from Can2Cluster or an OEM Hall Sensor and
converts it into a PWM signal for a BLDC motor using FreeRTOS multitasking.

Refactored to use:
- Native LEDC hardware PWM (driver/ledc.h) instead of ESP32_FastPWM
- FreeRTOS tasks for speed control (real-time), EEPROM, and WiFi management
- RunningMedian for capturing and filtering input pulses
- AsyncWebServer with API instead of ESPUI
- Global speed offset changed to curve with linear interpolation
*/

void setup()
{
    // Stop the motor drive IMMEDIATELY: GPIO2 floats at reset
    // so drive it low to stop random motor movement on boot  
    pinMode(pinMotorOutput, OUTPUT);
    digitalWrite(pinMotorOutput, LOW);

    // Sample the board-version strap (GPIO3) before anything else uses the pin.
    detectBoardVersion();

#if enableDebug
    Serial.begin(baudSerial);
    Serial.setTxTimeoutMs(10); // non-blocking TX: don't stall if no USB host is connected
    // Wait for the native USB-CDC to start
    uint32_t serialWaitStart = millis();
    while (!Serial && (millis() - serialWaitStart) < 2000)
    {
        delay(10);
    }
    DEBUG("====================================================");
    DEBUG(" SpeedPulser v%s  —  Forbes Automotive", VERSION);
    DEBUG(" FreeRTOS + LEDC + AsyncWebServer");
    DEBUG(" build: %s %s", __DATE__, __TIME__);
    DEBUG("====================================================");
#endif

    readEEP();          // Load saved settings from EEPROM
    calBuilderInit();   // Load any user (SpeedPulserV2) custom calibration 
    updateMotorArray(); // Update motor calibration array from EEPROM

    basicInit();     // Initialize GPIO, LEDC PWM, interrupts
    setMotorDuty(0); // Motor off initially

    // V4 board only: bring up the adjustable motor supply. The buck must be enabled
    // for the motor to have any voltage, so enable it regardless of the control
    // mode — starting at the minimum (safe) rail with the motor PWM already off.
    initVoltageControl();
    if (boardHasVoltageControl)
    {
        enableBuck();
        if (!voltageControlEnable)
        {
            setMotorVoltageCmd(vcVoltMax); // legacy PWM behaviour: hold full motor volts
        }
    }

    connectWifi();    // Enable WiFi and start AP/Station
    setupWebServer(); // Setup API web server and serve web files

    if (hasNeedleSweep)
    {
        needleSweep(); // Run needle sweep if enabled
    }

    // Universal reduced-power module (power_manager): 
    // turns WiFi off 1 min after the last client
    // disconnects then scales CPU 160->80 MHz, turns off Bluetooth and cuts current
    // draw through the system. Auto-detects LOLIN-C3 at compile time
    // (160 MHz cap, no LED pin).
    power_config_t pcfg = powerDefaultConfig();
    pcfg.verbose = (enableDebug && debugPower);
    powerInit(&pcfg);

    taskInit(); // start FreeRTOS tasks for speed control, EEPROM management

    DEBUG("setup complete — cal=%u maxSpeed=%u kph units=%s feedback=%s. Running.",
          (unsigned)motorPerformanceVal, (unsigned)maxSpeed,
          convertToMPH ? "mph" : "kph", feedbackEnable ? "ON" : "OFF");
}

void loop()
{
    // all work is done in tasks - this is just a placeholder
    // to keep the Arduino framework happy
    vTaskDelay(pdMS_TO_TICKS(1000));
    wifiManagerTick(); // Home WiFi (bridge mode): connection tracking + retry back-off
}

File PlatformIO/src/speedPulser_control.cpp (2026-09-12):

#include "speedPulser_control.h"
#include "speedPulser_defs.h"
#include "speedPulser_calBuilder.h"
#include "speedPulser_voltage.h"

// ===== Control Variables =====
volatile unsigned long dutyCycleIncoming = 0;
volatile TickType_t lastPulse = 0;   // FreeRTOS tick count — written in ISR
volatile uint16_t ledCounter = 0;    // counts incoming pulses for onboard LED flash
volatile uint32_t feedbackCount = 0; // feedback pulses — incremented in ISR

bool ledOnboard = false;
uint16_t dutyCycle = 0;
uint16_t appliedDutyCycle = 0;
uint16_t requestedSpeed = 0; // mapped/offset road speed (kph) that generates the applied duty
uint16_t tempDutyCycle = 0;  // calibration probe value, raw 12-bit hardware duty (0..PWM_DUTY_MAX)
int16_t currentSpeedOffset = 0;
uint16_t rawCount = 0;
bool testNeedleSweep = false;

RunningMedian samples = RunningMedian(10); // fixed max size for variable averageFilter (max 10)

void normaliseSpeedOffsetCurve()
{
  for (uint8_t i = 0; i < SPEED_OFFSET_CURVE_POINTS; i++)
  {
    speedOffsetCurveOffsets[i] = constrain(speedOffsetCurveOffsets[i], -20, 20);
  }
}

int16_t getCurveOffsetForSpeed(uint16_t speedKph)
{
  if (speedKph <= 50)
  {
    return speedOffsetCurveOffsets[0];
  }
  if (speedKph <= 100)
  {
    return speedOffsetCurveOffsets[1];
  }
  if (speedKph <= 150)
  {
    return speedOffsetCurveOffsets[2];
  }
  if (speedKph <= 200)
  {
    return speedOffsetCurveOffsets[3];
  }
  return speedOffsetCurveOffsets[4];
}

uint16_t applyConfiguredSpeedOffset(uint16_t speedKph)
{
  normaliseSpeedOffsetCurve();

  int32_t correctedSpeed = (int32_t)speedKph;
  int16_t offsetToApply = 0;

  if (useSpeedOffsetCurve)
  {
    offsetToApply = getCurveOffsetForSpeed(speedKph);
  }
  else
  {
    offsetToApply = speedOffsetPositive ? (int16_t)speedOffset : -(int16_t)speedOffset;
  }

  currentSpeedOffset = offsetToApply;
  correctedSpeed += offsetToApply;

  if (correctedSpeed < 0)
  {
    correctedSpeed = 0;
  }

  if (correctedSpeed > 400)
  {
    correctedSpeed = 400;
  }

  return (uint16_t)correctedSpeed;
}

// ===== Interrupt Handler =====
// Windowed frequency capture for the vehicle hall input. Deriving Hz from a single
// edge-to-edge period turns tone-wheel / tooth-spacing jitter straight into a jumpy
// reading, so instead the ISR accumulates the summed edge intervals and the interval
// count, and the task reads-and-clears the pair once per window: freq = count /
// summedInterval is a true average over the window — exactly how the closed-loop
// tacho (feedbackPulse) already works.
//
// File-scope (not a function-local static): a function-local static with a runtime
// initializer would emit a __cxa_guard_acquire on first use, which takes a FreeRTOS
// mutex with a timeout — illegal in an ISR and asserts in queue.c.
struct PulseWindow
{
  volatile uint32_t accumUs;    // summed edge-to-edge intervals (us) this window
  volatile uint32_t count;      // number of intervals summed into accumUs
  volatile uint32_t lastEdgeUs; // micros() of the previous accepted edge (kept across windows)
};

static PulseWindow hallPulse = {0, 0, 0};

// Reject edges closer together than this. Ignition-coil EMI couples in as
// sub-millisecond bursts, while a real input edge tops out around 230 Hz (~4.3 ms),
// so anything faster than ~3 ms (333 Hz) can't be a genuine pulse and is dropped.
static const uint32_t PULSE_MIN_INTERVAL_US = 3000;

// Guards the read-and-clear of the pulse window against the ISR. portMUX is the
// FreeRTOS/ESP32-safe primitive; a global noInterrupts() would starve the WiFi radio.
static portMUX_TYPE hallPulseMux = portMUX_INITIALIZER_UNLOCKED;

// Accumulate one edge into a window. Returns true when the edge was accepted (it
// advanced the average), false when it merely seeded the window or was rejected as
// a glitch. lastEdgeUs is kept on a glitch so the next real edge still measures from
// the last good edge.
static inline bool IRAM_ATTR pulseEdge(PulseWindow &w, uint32_t now)
{
  uint32_t last = w.lastEdgeUs;
  if (last == 0)
  {
    w.lastEdgeUs = now; // seed on the first pulse only
    return false;
  }
  uint32_t interval = now - last;
  if (interval < PULSE_MIN_INTERVAL_US)
    return false; // coil EMI / bounce: ignore, keep the last good edge
  w.accumUs += interval;
  w.count++;
  w.lastEdgeUs = now;
  return true;
}

// Read-and-clear a window, returning its averaged frequency in Hz, or -1 when no
// fresh edges arrived (caller should hold the previous value). lastEdgeUs is left
// intact so the next window's first interval bridges from this window's last edge.
static float readPulseHz(PulseWindow &w)
{
  portENTER_CRITICAL(&hallPulseMux);
  uint32_t count = w.count;
  uint32_t accum = w.accumUs;
  w.count = 0;
  w.accumUs = 0;
  portEXIT_CRITICAL(&hallPulseMux);
  if (count >= 1 && accum > 0)
    return (float)count * 1000000.0f / (float)accum;
  return -1.0f;
}

// Full reset (including the edge reference) — used on timeout / test transitions so
// a stale lastEdgeUs can't inject one bogus huge-interval reading when input resumes.
static void resetPulseWindow(PulseWindow &w)
{
  portENTER_CRITICAL(&hallPulseMux);
  w.accumUs = 0;
  w.count = 0;
  w.lastEdgeUs = 0;
  portEXIT_CRITICAL(&hallPulseMux);
}

static float readHallHz() { return readPulseHz(hallPulse); }
static void resetHallPulseCounter() { resetPulseWindow(hallPulse); }

// Interrupt routine for the incoming pulse from opto-isolator.
// IRAM_ATTR is required: this fires from a GPIO interrupt and must be able to
// run while the flash cache is disabled (e.g. during an EEPROM/LittleFS write).
void IRAM_ATTR incomingHz()
{
  // Ignore the vehicle hall input entirely while bench-testing or calibrating —
  // the motor is driven from the Speed Test / Cal controls, so an incoming signal
  // must not touch the window, lastPulse or the LED counter until the test
  // (or cal) is turned off.
  if (testSpeedo || testCal)
    return;
  if (pulseEdge(hallPulse, micros()))
  {
    lastPulse = xTaskGetTickCountFromISR(); // FreeRTOS-safe tick snapshot
    ledCounter++;                           // count for LED flashing
  }
}
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

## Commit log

2026-03-13 Releases
    Added
    [partitions.csv]
2026-03-16 V1.20
    Smiths 150mph cluster
    [MotorPerformance.xlsx]
2026-06-29 V2.21
    Added power management
2026-07-18 V3.00
    Added BMW 2002 cluster & motor feedback (for future PCB)
2026-08-09 V3.10
    Calibration builder/UI/etc readme changes.
2026-08-09 V3.10
    Added Calibration Builder, UI changes, feedback etc.
2026-08-09 V3.10
    Calibration Builder, Calibration Curve, UI changes, OTA etc.
2026-08-15 V3.10
    Mistake on the interrupt caused crash.
    [speedPulser_control.cpp, speedPulser_motorCal.cpp]
2026-08-15 V3.10
    Revised build for interrupt failure.
2026-10-13 V5.01 - Drive Calibration
    Updated motor voltage control (legacy boards still supported).
2026-10-13 V5.01
    Motor voltage control
